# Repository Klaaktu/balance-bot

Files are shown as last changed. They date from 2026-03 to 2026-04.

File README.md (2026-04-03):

# PHS6701 Project 1 - Balance Bot

## Dependencies

Install these in Arduino IDE Library Manager
- Adafruit MPU6050 (IMU: Gyro + Acc)
- QMC5883LCompass by MPrograms (Magnetometer)
- Adafruit AHRS (Sensor fusion for absolute yaw)
- L298N by Andrea Lombardo (Motor driver)
- AdvancedPID by Alby312

## Calibration

You can remove the wheels so that it can sit flat on the ground.

## Libraries (for v1 code)

Version 1 uses code suggested by the instruction sheet, which is not in the Library Manager.

Copy the content of the `libraries` folder into the `libraries` folder in your Arduino sketchbook location (In Arduino IDE). You cannot have other libraries of the same functions installed or it's going to create a conflict.

## Notes
InvenSense has proprietary DMP 9-axis fusion which no one has working on Arduino. Open algorithm with I2C bypass works just as well. But you need raw readings, so can't use DMP or its interrupt. (The Adafruit lib doesn't support DMP readings either.)

MPU6050 max sample rate is 1kHz.

[Alternative rates](https://github.com/kriswiner/MPU9250/issues/363#issuecomment-502226744):
1k IMU and 100 mag, update rate 5k. Adafruit used 104Hz for IMU and 1k for mag, update rate 100Hz.

RIP, embedded software's documentations are so poor...

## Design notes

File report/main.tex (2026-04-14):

\documentclass[9pt,a4paper,twocolumn]{tau-class/tau}

\usepackage{listings}

\lstset{language=C++}

\title{Design a Robot with Balancing Ability and Self-controllability}

\author{Zhihao Lin\thanks{u8175491@anu.edu.au}}
\author{Zongjun Yang\thanks{u8463895@anu.edu.au}}

\affil[1]{Research School of Physics, Australian National University, Canberra ACT, 2601, Australia}

% \begin{abstract}
% \end{abstract}

\begin{document}

\maketitle

\section{Executive Summary / Abstract}
This report presents a comprehensive design review of an autonomous two-wheeled self-balancing robot, including system architecture, physical modeling, and current prototype progress. The primary objective is to develop a robot capable of maintaining dynamic balance, resisting external perturbations, and executing controlled motion. 

The proposed system architecture is driven by an Arduino UNO with a high-frequency Proportional-Integral-Derivative (PID) feedback control. Real-time spatial states sensing is acquired via an $I^2C$ MPU-6050 IMU. Actuation is delivered by two geared DC motors controlled by an L298N motor driver. Furthermore, the 3D-printed physical chassis was modeled using Lagrangian mechanics, intentionally increasing the height of mass center to lower the falling speed and provide the processor a temporal window for actuation.

As of Week 6, the project is progressing ahead of schedule. The physical prototype has been fully assembled, and the core balancing functionality has been successfully demonstrated. The robot can maintain steady-state equilibrium indefinitely with minimal drift ($<0.15m$ in 1s). While the current hardware configuration recovers from disturbances up to only $13^\circ$ (less than the $15^\circ$ target), the direction of mechanical and control improvements have been identified to resolve this during the next phase.

Moving forward, the team has transitioned to a concurrent engineering approach to develop advanced mobility and adaption skills in parallel. A revised timeline is used to map the final integration and comprehensive testing phases across Weeks 7-12.

\section{Introduction}

\subsection{Background}
There are increasing applications that need robots to participate. For example, complicated transportation in lab environments \cite{application_lab_transportation_liu_2013}, security support with interaction ability \cite{application_security_lopez_2017}, and educational communication \cite{application_social_tony_2018}. With the revolution of machine learning and artificial intelligence, robots are becoming much more intelligent \cite{ai_soori_2023, mobile_robot_raj_2022}, which will be applied to wider field.

Fundamentally, a robot requires several characteristics including: it must be produced by manufacture, it must be able to move itself or other objects, and it must be able to respond to its environment \cite{fundamental_todd_2012}. This indicates the essential parts of a robot: physical bodies, action drivers, sensors, and processors (controllers). Mobile robot is a typical case of both robot definition and robot applications \cite{mobile_robot_tzafestas_2018, mobile_robot_raj_2022}. 

To implement robots to everyday applications, we need to start from a prototype, and upgrade it step by step. The objective of this project is to design, fabricate, and program an autonomous robot with excellent balancing performance and high controllability. 

\subsection{Requirements Review}
\label{subsec:requirements_review}
The primary objective of this project is to build an autonomous self-balancing robot which is able to move to or keep itself around a designated position. To achieve this, the listed specific requirements are as follows:
\begin{itemize}
	\item Top-level requirements: \begin{itemize}
	\item The robot must maintain its balanced position without any falling cases.
	\item If the robot is perturbed externally (e.g., a deliberated push, or an obstacle collided), it must be able to return balanced within $2s$. The perturbation is defined as changing its pitch angle up to $15^\circ$.
	\item Without perturbation, the robot must balance itself in a small range. It must not move more than $0.5m$ in $1s$.
	\end{itemize}

	\item Electronic components:\begin{itemize}
	\item The robot must be able to sense its angle or velocity at $>100Hz$. The resolution of angle must be $<0.5^\circ$.
	\item The robot must take action within $0.1s$ after a controlling signal is sent.
	\item The electronics must be stable during its runtime.
	\item After turning on,  the robot must work entirely independently, including power supply, signal processing, and controlling.
	\end{itemize}

	\item Physical structure:\begin{itemize}
	\item The structure must be stable enough that the position of mass center doesn't change.
	\item The chassis must be sturdy, which can resist damage when the robot falls in some cases.
	\end{itemize}
  
  \item Advanced requirements: \begin{itemize}
  \item The robot can be able to fully control its state, including facing direction and moving speed.
  \item The robot can follow a designated path without obvious drift.
  \item The robot can dynamically adapt its response to varying operational environments: in peaceful environments, being slightly perturbed, being strongly perturbed, commanded to move to and keep around a position. 
  \end{itemize}
\end{itemize}

\section{Technical Details and Analysis}

\subsection{System Architecture}
\label{subsec:basic_ideas}

\figref{fig:basic_balancing_flowchart} shows the flowchart of the basic balancing idea of the robot. Generally, it shows the realization of the basic balancing skills. Any other advanced skills can be add to these parts. Reading multiple types of states (e.g., pitch angle, yaw angle, and x-acceleration) can be add in the "Read State" process. "Check States" decision can be used to assess the situation of the robot. "Feedback Controller" process can handle different controllers, such as PID controller. "Take Action" process controls the states of the robot.

\begin{figure}[htbp]
    \centering
    
    \caption{Flowchart of basic balancing logic. After turning on, the robot keeps reading its state, such as the pitch angle or the angular velocity of y-axis. If it's not strongly unbalanced, feedback controllers are used to generate an output from the state. The output is used to control the robot, such as moving forward or turn left. The feedback loop can balance the robot theoretically.}
    \label{fig:basic_balancing_flowchart}
\end{figure}

We started from developing the basic balancing skill. When this first stage was completed successfully, we would try to realize the advanced requirements by upgrading the existed processes or decisions instead of rebuild a new structure. In this way, the development would be controllable and the progress would be clear. However, a new structure can be required if we want to develop a more complex logic.

\subsection{Electronic Components}
To achieve the main goal, the electronic components should contain these necessary parts: a state sensor, a central processor, an action driver, and power supply.

\subsubsection{The state sensor}
We use MPU-6050 inertial measurement unit (IMU) as the state sensor. It consists of a triple-axis gyroscope and a triple-axis accelerometer. Using the angular velocities and linear accelerations, we can get or calculate most of the important states of robot. The key parameters of MPU-6050 are listed in \tabref{tab:mpu6050_specifications}:

\begin{table}[htbp]
    \centering
    \begin{tabular}{c c c}
    \toprule
    \textbf{Parameter} & \textbf{Value} & \textbf{Unit} \\
    \midrule
    Gyroscope Full-scale Range & $\pm250$ & $^\circ/s$\\
    Gyroscope Sensitivity & $131$ & $LSB/(^\circ/s)$\\
    Gyroscope Noise Spectral Density & $0.005$ & $^\circ/s/\sqrt{Hz}$\\
    Gyroscope Output Rate & $8000$ & $Hz$\\
    \midrule
    Accelerometer Full-scale Range & $\pm2$ & $g$\\
    Accelerometer Sensitivity & $16384$ & $LSB/g$\\
    Accelerometer Noise Spectral Density & $400$ & $\mu g/\sqrt{Hz}$\\
    Accelerometer Output Rate & $1000$ & $Hz$\\
    \midrule
    Supported Communication & $I^2C$ & \\
    Communication Speed & $400$ & $kHz$ \\
    Clocking Speed & $32.768k\sim19.2M$ & $Hz$ \\
    \midrule
    Power Input Voltage & $2.375\sim3.46$ & $V$ \\
    \bottomrule
    \end{tabular}
    \vspace{\baselineskip}
    \caption{The key parameters of MPU-6050 inertial measurement unit \cite{mpu6050_datasheet}}
    \label{tab:mpu6050_specifications}
\end{table}

The best resolution of angular velocity can reach $7.6\times10^{-3}\;^\circ/s$, and the best resolution of acceleration can reach $61\times10^{-6}\;g$. Ignoring the noise, these resolutions are totally sufficient for the requirements. Both the sampling rate and communication speed satisfy our requirements. The primary limitation of this IMU is the inherent sensor noise or drift. Considering the noise, we can try to process the signal (such as low-pass filter or quaternion) to get high enough resolution. 

\subsubsection{The central processor}
Arduino UNO is chosen as the processor. We can use it to get data from the IMU, process the data, and control the action driver. Its key parameters are listed in \tabref{tab:arduino_uno_specifications}:

\begin{table}[htbp]
    \centering
    \begin{tabular}{c c c}
    \toprule
    \textbf{Parameter} & \textbf{Value} & \textbf{Unit} \\
    \midrule
    \# Digital I/O Pins & $14$ & \\
    \# Analog Input Pins & $6$ & \\
    \# PWM Pins & $6$ & \\
    \midrule
    Supported Communication & $I^2C$, $SPI$, $UART$ & \\
    Clocking Speed & $16$ & $MHz$ \\
    \midrule
    Power Output Voltage & $3.3$, $5$ & $V$ \\
    Power Input Voltage & $7\sim12$ & $V$ \\
    \bottomrule
    \end{tabular}
    \vspace{\baselineskip}
    \caption{The key parameters of Arduino UNO \cite{arduino_uno_datasheet}}
    \label{tab:arduino_uno_specifications}
\end{table}

The number of digital, analog and PWM pins are enough for the wiring connecting the processor to the sensor and the action driver. The high processing speed is ideal for our control logic. Using $I^2C$ communication and $3V3$ output power, it can match the MPU-6050 very well. However, the power output voltage may not be enough for some action drivers. So a shared power supply may be required. 

\subsubsection{The action driver}
We choose to use a L298N motor driver and two geared DC motors. The key parameters of the L298N motor driver are listed in \tabref{tab:l298n_specifications}:

\begin{table}[htbp]
    \centering
    \begin{tabular}{c c c}
    \toprule
    \textbf{Parameter} & \textbf{Value} & \textbf{Unit} \\
    \midrule
    Digital Input Pins & $IN1+IN2$, $IN3+IN4$ & \\
    PWM Input Pins & $ENA$, $ENB$ & \\
    \midrule
    Logic Input Voltage & $5$ & $V$ \\
    Power Output Voltage & $3.2\sim40$ & $V$ \\
    Power Input Voltage & $5\sim35$ & $V$ \\
    \bottomrule
    \end{tabular}
    \vspace{\baselineskip}
    \caption{The key parameters of L298N motor driver \cite{l298n_datasheet}}
    \label{tab:l298n_specifications}
\end{table}

The motor driver allows PWM input, which matches well with the Arduino UNO. The digital input pins can be used to control the direction of motors, while the PWM input pins can be used to control the speed. The required voltage is high as expected, so a good power supply is needed. However, by experiments, we found that the motors can keep still when the speed signal is small, which is caused by the internal static friction. Feed-forward controller can be added to solve this dead-band. Moreover, the two motors have a little asymmetry, which makes the robot yaw. Therefore, stepper motors can be required when we need to do precise control or measurement.

\subsubsection{Power supply}
We need to supply power to both the Arduino UNO and the motor driver. Therefore, two 800mAh 3.7V rechargeable Li-ion cells are used. For reusability, we use a breadboard to transfer the power from batteries to the two components instead of soldering the wires. The safe charged voltage of Li-ion is $2.8\sim4.2\;V$. By testing, the batteries need to be recharged after working for about 10 hours. 

\subsubsection{Wiring structure}
As mentioned above, the electronic components used are: 
\begin{itemize}
  \item MPU-6050 IMU
  \item Arduino UNO
  \item L298N motor driver
  \item Geared DC motors
  \item Li-ion Batteries
  \item Breadboard
\end{itemize}
The wiring method is shown in \figref{fig:wire_diagram}.

\begin{figure}[htbp]
    \centering
    
    \caption{Wiring diagram of the electronic components. The battery and breadboard are used to power the Arduino UNO and L298N motor driver. UNO communicates with MPU-6050 inertial measurement unit (IMU) using I2C protocol, and sends analog signal to the motor driver using pulse width modulation (PWM). The motor driver controls 2 motors.}
    \label{fig:wire_diagram}
\end{figure}

\subsection{Mechanical Design}

\subsubsection{Physical model analysis}
\figref{fig:physical_model} shows the simplified physical model of the robot. We can use Lagrangian mechanics to analyze the relationship between $F$ and $\theta$, $x$. The system Lagrangian and Euler–Lagrange equations are given by:
\begin{equation}
	L=\frac{1}{2}M\dot{x}^2+\frac{1}{2}m\left[(\dot{x}+l\dot{\theta}\cos{\theta})^2+(l\dot{\theta}\sin{\theta})^2\right]-mgl\cos{\theta}
\end{equation}
\begin{align}
	\frac{d}{dt}\frac{\partial L}{\partial\dot{x}}-\frac{\partial L}{\partial x}=F\quad&\Longrightarrow\quad(M+m)\ddot{x}+ml\ddot{\theta}\cos{\theta}-ml\dot{\theta}^2\sin{\theta}=F\label{eq:el_eq1}\\
	\frac{d}{dt}\frac{\partial L}{\partial\dot{\theta}}-\frac{\partial L}{\partial\theta}=0\quad&\Longrightarrow\quad \ddot{x}\cos{\theta}+l\ddot{\theta}-g\sin{\theta}=0\label{eq:el_eq2}
\end{align}

\begin{figure}[htbp]
    \centering
    
    \caption{A simplified physical model of the robot. Constrain the movement in 1 dimension. THe model consists of a wheel with mass $M$, a body mass center $m$, and a light stick connecting these two with length $l$. The action of wheel is simplified as a force $F$. Assume the robot is at position $x$ and its pitch angle is $\theta$.}
    \label{fig:physical_model}
\end{figure}

Usually, we care about the dynamic of $\theta$, which can be derived from \equref{eq:el_eq1} and \equref{eq:el_eq2}:
\begin{equation}
	\ddot{\theta}=\frac{(M+m)g\sin{\theta}-F\cos{\theta}}{(M+m\sin^2{\theta})l}-\frac{m\dot{\theta}^2\sin{2\theta}}{2(M+m\sin^2{\theta})}
    \label{eq:theta_dynamic}
\end{equation}

According to the model \figref{fig:physical_model} and this \equref{eq:theta_dynamic}, we can analyze some cases:
\begin{itemize}
	\item The robot is perfectly at the balanced state, but a perturbation happens before the controller realizes it (i.e., $\theta\gtrapprox0$, $F=\dot{\theta}=0$). In this case, $\ddot{\theta}\approx\frac{(M+m)g\sin{\theta}}{lM}$. To maximize the controller's temporal response window before $\theta$ reaches an unbalanceable angle, we want $\ddot{\theta}$ to be as small as possible, which means we need to use small $m$ and/or large $l$.
	\item The robot is in a state of dynamic equilibrium (i.e., $\theta>0$, $\ddot{\theta}\approx\dot{\theta}\approx0$). To keep a constant $\theta$, it's necessary to make $F=(M+m)g\tan{\theta}$. However, because of the limit of motor power, $F$ can be maintained for only a short time before the large speed brings large resistance. So we should make $F>(M+m)g\tan{\theta}$ to bring back balance before the saturation of motors.
	\item The robot is severely unbalanced (i.e., $\theta>0$, $\dot{\theta}>0$). In this case, the only possible way to balance the robot is to make $\ddot{\theta}$ as negative as possible (i.e., $\ddot{\theta}\ll0$). To achieve this, we need to use a combination of large $F>(M+m)g\tan{\theta}$ and small $l$.
	\item The robot is inverted (i.e., $90^\circ<\theta<270^\circ$ ($l<R_\text{wheel}$), $l=0$, or $m=0$). Now the robot is impossible to return to the desired balanced state (or the balanced state can't be defined), but becomes permanently stable.
\end{itemize}
In conclusion, a motor being able to produce huge $F$ is wanted for all the cases. Similarly, it's good to have small $m$, $M$, and/or $\frac{m}{M}$. Large $l$ is suitable for peaceful environment and high balance performance, while small $l$ or inverted robot is suitable for severe environment and high controllability. 

\subsubsection{Chassis}
We use CAD (Autodesk Fusion) to design the chassis model, and 3D-print the model. The chassis is designed with many components in the experimental stage to make some components easier to update. These components are assembled using M3 bolts and nuts. For the final design, all the components are combined into a whole one to make the chassis stable.

In Fusion, the chassis is designed with the help of the models of other electronic components. Official datasheets of the electronic components are also used. In this way, it's precise and accurate to design the size and position of chassis components and through holes. One of our CAD model designs is shown in \figref{fig:chassis_design}. It has high mass center, which can perform good balancing skill but lack flexibility.
\begin{figure}[htbp]
  \centering
  \begin{subfigure}{0.8\columnwidth}
    
    \caption{Front-top-side view}
  \end{subfigure}

  \vspace{\baselineskip}

  \begin{subfigure}{0.8\columnwidth}
    
    \caption{Robot components and assembly}
  \end{subfigure}
  \caption{A chassis model design.}
  \label{fig:chassis_design}
\end{figure}

PrusaSlicer is used to convert CAD models to 3D-printing code. The printer uses PLA as the filament with diameter of $1.75mm$. To make our chassis sturdy, we use layer height of $0.3mm$. The vertical shells is set to 4 perimeters, and the horizontal shells is set to 4 top layers and 4 bottom layers. Since most of our chassis consist of plates of $3mm$, these parameters are sufficient to make our chassis solid. The fill density is set to $15\%$. The only disadvantage is that solid chassis may increase the mass. We compensated it by change the height of mass center by a larger value.

\subsection{Signal Processing}

\subsubsection{IMU data processing}
To get the robot state, we need to process the data from the IMU. The IMU contains a 3-axis gyroscope used to measure angular velocity and a 3-axis accelerometer used to measure acceleration. One important thing we can do is to get the angle (yaw, pitch, roll) from these values. Simply, we can integrate the 3 angular velocities $(\omega_x,\omega_y,\omega_z)$ to get the corresponding Euler angle. However, Euler angles suffer from Gimbal Lock, resulting in the loss of a degree of freedom and causing ambiguous calculations (for example, the results are the same whether it yaws by $30^\circ$ and then pitches by $90^\circ$, or pitches by $90^\circ$ and then rolls by $30^\circ$, which makes it difficult to determine the true yaw or roll angle). Because of this, we use quaternion $q=(q_0,q_1,q_2,q_3)$ to represent the angle state, which indicates the current state that is equivalent to rotate the initial state around an axis $(q_1,q_2,q_3)$ by an amount of $q_0$. The current quaternion is given by:
\begin{equation}
	q_n=q_{n-1}+\frac{\Delta t}{2}\cdot q_{n-1}\otimes\omega
\end{equation}

Another method to get quaternion is using the accelerations $(a_x,a_y,a_z)$. Because there is a constant gravity of $\approx9.8m\cdot s^{-2}$, we can know the quaternion by comparing the direction of measured acceleration with the true gravity. However, this method is noisy, while using gyroscope can produce drift over a long time. We can mitigate the high-frequency noise of accelerometers by a low-pass filter, and the low-frequency drift of gyroscopes by a high-pass filter, which is called complementary filter.

There are many states we can calculate from the quaternion (Most calculations can be done by the IMU module or some libraries such as \texttt{i2cdevlib/Arduino/MPU6050}). For example:
\begin{align}
	\text{Pitch: }&\theta=\arcsin{(2(q_0q_2-q_3q_1))}\\
	\text{Yaw: }&\psi=\arctan{\frac{2(q_0q_3+q_1q_2)}{1-2(q_2^2+q_3^2)}}\\
	\text{Acceleration: }&a_\text{world}=q\otimes(0,a_x,a_y,a_z)\otimes q^{-1}
\end{align}

In this way, we can get the tilt angles or accelerations much more precisely and unambiguously. However, to get the displacement of the robot, we need to integrate the acceleration twice, which can brings huge noise and drift. This disadvantage is mostly caused by the hardware, which is hard to improve by software. Therefore, we can choose to calculate the displacement from the signal used to control the speed of motors.

\subsubsection{PID controller}
PID (Proportional-Integral-Derivative) controller is the core of the feedback system. By comparing the current state $S(t)$ with the desired state, we get an error term $e(t)$. Using $e(t)$ as the input of PID controller, we can use the output $u(t)$ to drive the current state toward the desired state. The output expression is given by:
\begin{equation}
	u(t)=K_pe(t)+K_i\int_{0}^{t}{d\tau\,e(\tau)}+K_d\frac{de(t)}{dt}
\end{equation}

The Proportional term means that the larger the error is, the large the output is to restore the state. The Integral term means that the longer the error persists, the large the output is to further restore the state. The Derivative term means that the faster the error decreases, the smaller the output is to reduce oscillation. The three terms have individual coefficients ($K_p$, $K_i$, $K_d$). Their combinations vary widely across different situations.

For the PID of balancing pitch angle, the 3 coefficients need to be tune along with the balanced pitch angle $\theta_0$. First, we found the approximate pitch angle. Based on this, we adjusted only $\theta_0$ and $K_p$ until the robots fell in both directions with a similar low probability, which means $\theta_0$ is closed to the true balanced pitch angle. Then, we tuned $K_d$ such that the robot wouldn't oscillate too much around the $\theta_0$. However, the robot may occasionally keep moving in one direction. We used large $K_i$ to correct it. The optimal tuning yields highly varied coefficients. For example, $K_p=48$, $K_i=600$, and $K_d=0.19$ with PID sample time $=2ms$. By tunning these coefficients and looking for a good balancing state, we can achieve better feedback performance. 

\subsubsection{Pulse width modulation}
In order to control the robot smoothly and continuously, we need analog signals to do the task. However, the UNO has only digital output, which means the output voltage can be either HIGH level or LOW level without any values in between. PWM can solve this problem. Instead of encoding signals to voltage level, it produces a train of pulses as the output, and encodes signals to the width of each pulse. Meanwhile, our motor driver is able to receive the PWM signals.

However, the range of PWM values is limited. This disadvantage can be ignored in our cases, since the resolution of PWM is much better than the resolution of geared motors.

\subsection{Control Logic}
The program for controlling runs in Arduino UNO. The structure of control logic is based on \ref{subsec:basic_ideas} and \figref{fig:basic_balancing_flowchart}, whose details are shown below:

\subsubsection{Start}
In this initialization sequence, all the components are configured. If anyone of them is not initialized successfully, the following controlling code would not run.
\begin{itemize}
  \item \texttt{initImu()}: Sets the offsets of 3 axises for the gyroscope and the accelerometer, and waits until the IMU becomes stable.
  \item \texttt{initPID()}: Defines the balanced pitch and yaw, the PID coefficients for different situations, and the PID object for pitch and yaw.
  \item \texttt{initMotor()}: Uses \texttt{pinMode(pin, mode)} to initialize 2 EN pins and 4 IN pins.
\end{itemize}

\subsubsection{Read States}
In this process, we get the states of the robot from the calculations about quaternion. The logical code is shown in \coderef{lst:code_read_states} For pitch and yaw angles, we calculate the error between the true angle and the balanced angle, unwrap the $2\pi$ period, and use the result as the input of feedback control. For accelerations, we compute the value in the world frame using the quaternion.

\begin{lstlisting}[caption={Example code of "Read States" process}, label={lst:code_read_states}]
double unwrapAngle(float angle, double balanced) {
  double a = angle * 180 / M_PI - balanced;
  // ... unwrap from 2*pi ...
}
bool getRobotState() {
  imu.dmpGetQuaternion(&quaternion, imuFifoBuffer);
  imu.dmpGetYawPitchRoll(imuYpr, &quaternion, &gravity);
  pitchAngle = unwrapAngle(imuYpr[1], balancedPitch);
  // ... doing similar jobs for yaw and acceleration ...
  imu.dmpGetLinearAccelInWorld(...);
}
\end{lstlisting}

\subsubsection{Check States}
The states gotten from the previous process is analyzed, and the next step is determined. For example (as shown in \coderef{lst:code_check_states}), the coefficients of PID controller will dynamically transition to surviving mode (high-gain feedback) if the pitch angle is too large, or the motors will be disabled if the robot is destined to fall.

\begin{lstlisting}[caption={Example code of "Check States" process}, label={lst:code_check_states}]
if (abs(pitchAngle) > maxPitchAngle) { motorStop(); }
// ...
if (abs(pitchAngle) > survivingPitch) {
  pitchPID.SetTunings(sKp, sKi, sKd);
} else { pitchPID.SetTunings(kp, ki, kd); }
\end{lstlisting}

\subsubsection{Feedback Control}
Our feedback control is currently based on only PID controller. We use a library to manage the computing. In the code, the feedback output can be gotten from \texttt{pid.Compute()}. The code is simple, while this process is essential to the robot. All the coefficients need plenty of time to tune manually.

\subsubsection{Take Action}
This process convert the digital signals from feedback control into a real action of the robots. For example, accelerating immediately, or rotating clockwise slowly. The action is also influenced by "Check States". As shown in \coderef{lst:code_take_action}, balancing the pitch is a priority over adjusting the yaw.
\begin{lstlisting}[caption={Example code of "Take Action" process}, label={lst:code_take_action}]
if (abs(motorValue) > maxMotorValue * 0.3) {
  motorMove(motorValue, ENA_PIN, IN1_PIN, IN2_PIN);
  motorMove(motorValue, ENB_PIN, IN3_PIN, IN4_PIN);
} else {
  motorMove(motorValue + yawCorrection, ENA_PIN, ...);
  motorMove(motorValue - yawCorrection, ENB_PIN, ...);
}
\end{lstlisting}

\section{Prototype Progress}

\subsection{Current Prototype Capabilities}

During the last 6 weeks, we have finished these tasks: connecting and initializing each components, reading angles and accelerations from IMU, using PWM to driver motors, balancing the robot by its pitch angle with PID, controlling the yaw angle basically.

The robot of current version is shown in \figref{fig:robot_balancing_on_table}. 

\begin{figure}[htbp]
    \centering
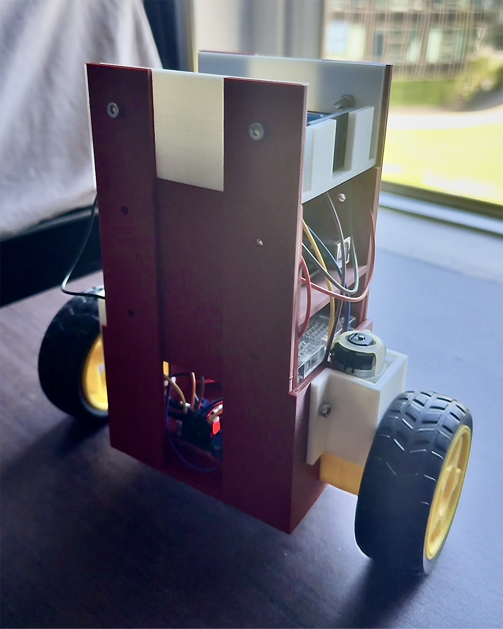
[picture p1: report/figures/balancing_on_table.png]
    
    \caption{The robot with complete basic balancing skills and preliminary advanced skills. It can stably balance itself on a small table.}
    \label{fig:robot_balancing_on_table}
\end{figure}

Preliminary performance metrics of the current prototype are listed in \tabref{tab:robot_evaluation_metric}. Most top-level requirements mentioned in \ref{subsec:requirements_review} are achieved. Some evaluations are even better than expected, such as the max displacement in 1s  without perturbation. However, the max allowed perturbation pitch ($<15^\circ$) is not achieved. It's because the high mass center can weaken its perturbation resistance. To improve this skills, we will try to increase the strength of motor driver, increase the wheel size, or decease the mass and the height of mass center.

\begin{table}[htbp]
    \centering
    \begin{tabular}{c c}
    \toprule
    \textbf{Evaluation Metric} & \textbf{Rough Value} \\
    \midrule
    Balancing Time (no perturbation) & $\sim\infty$ \\
    Max Pitch (no perturbation) & $\approx3.5^\circ$ \\
    Max Displacement in $1s$ (no perturbation) & $\approx0.15\;m$ \\
    Min Pitch to Drive Motors & $<0.4^\circ$ \\
    \midrule
    Perturbation Reaction Time & $\ll0.2\;s$ \\
    Max Allowed Perturbation Pitch & $\approx13^\circ$ \\
    Max Time to Restore from Pitch Perturbation & $\approx1.5\;s$ \\
    Max Displacement by Pitch Perturbation & $\approx1\;m$ \\
    Max Time to Restore from Yaw Perturbation of $180^\circ$ & $\approx3\;s$ \\
    \bottomrule
    \end{tabular}
    \vspace{\baselineskip}
    \caption{Some key evaluations of the robot of current version.}
    \label{tab:robot_evaluation_metric}
\end{table}

\subsection{Current State}
It's the 6th week. We are mainly focusing on the reports and the review of the last 6 weeks. Meanwhile, we also start to design or improve the prototype to achieve the advanced requirements. These tasks are being done: controlling the yaw angle with high flexibility, and controlling the linear motion at a constant speed with good balance performance. 

\section{Project Management}

\subsection{Responsibilities}
Initially, the project was divided into two parts: hardware and software. The origin responsibilities are listed below:
\begin{itemize}
  \item Lin: hardware part, including electronic components and mechanical design
  \item Yang: software part, including signal processing and control logic
\end{itemize}
However, our progress was unexpectedly fast. The first version of balancing robot was developed much earlier than planned. After discussions, we both agreed that designing the hardware and software together is much more efficient than designing them individually and then combining them. By team working and peer learning, we quickly mastered both the hardware and software part. Therefore, we use a semi-parallel structure for our project. Both of us is responsible to design a robot with different skills individually while sharing the same mechanical and logical architecture. There are also regular discussions about integrating these skills into one robot. Our current responsibilities about skill designing are listed below: 
\begin{itemize}
  \item Lin:\begin{itemize}
    \item Locking skill: the robot can lock itself to a certain direction, even if it's rotated by us deliberately.
    \item Adaption skill: the robot can judge the situation that it's facing or will face.
  \end{itemize}
  \item Yang:\begin{itemize}
    \item Motion skill: the robot can move forward and backward actively while keeping balanced.
    \item Resurrection skill: the robot can restore itself from a heavy perturbation.
  \end{itemize}
\end{itemize}
Combining these skills, we can achieve the advanced requirements mentioned in \ref{subsec:requirements_review}

\subsection{Estimated Timeline}
The remaining development will be divided into 3 phases:
\begin{itemize}
  \item Phase 1: Improve the locking skill and motion skill. Combine them into one robot.
  \item Phase 2: Develop the adaption skill and resurrection skill. Discuss the development plans in the beginning, and combine the development results at the end.
  \item Phase 3: Conduct comprehensive tests. Do the final improvements based on the performance.
\end{itemize}
The detailed timeline is shown in \figref{fig:timeline_gantt_chart}
\begin{figure}[htbp]
    \centering
    
    \caption{The Gantt chart of our estimated timeline.}
    \label{fig:timeline_gantt_chart}
\end{figure}

\subsection{Budget}
The project was designed to be cost-efficiency for rapid prototyping, utilizing off-the-shelf hardware and open-source software libraries. While the primary components were provided for this study, the total retail cost for the electronics and mechanical parts is approximately \$120 AUD. Additionally, iterating the chassis design via 3D printing cost less than \$5 AUD in material costs. This low-cost approach ensures the platform remains accessible for replication and future development.

\section{Conclusion}
This design review has detailed system architecture, mathematical and physical foundations, and developmental progress of an autonomous balancing robot. By leveraging a Lagrangian dynamic model, the physical chassis was currently optimized with an elevated center of mass. System requirements have been addressed through a robust electronics stack, utilizing an $I^2C$ MPU-6050 IMU. A 500 Hz PID control loop effectively translates error calculations into physical restoration via the L298N motor drivers. Current prototype testing confirms the viability of this design; the robot successfully maintains steady-state dynamic equilibrium with minimal drift and recovers from impulse perturbations up to $13^\circ$.

While the current perturbation resistance falls marginally short of the $15^\circ$ target, the identified hardware limitations provide a clear pathway for refinement. As the project enters the final phases of development, the transition to a concurrent engineering strategy ensures that advanced mobility and adaptation skills will be integrated efficiently.

\printbibliography

\end{document}

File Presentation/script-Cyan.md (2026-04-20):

I should **first acknowledge** that I'm basically being carried by my teammate here. What's been completed **is all his work**. I have some **ideas but unfortunately** I didn't have time to finish them. But I'll **integrate** those ideas to the presentation.

# Chassis

So um, I made another iteration of the chassis in **FreeCAD**. It's meant to be more **modular** and **lighter** plus some **minor improvments**. However the biggest **problem** I created is that it's hard to **assemble** because the **screws** are hard to access. I plan to change to **horizontal screw tabs** next time.

# Signal Processing: IMU

**The IMU has** gyroscopes and accelerometer, and in some chip packages like mine, has a magnetometer as well. The **gyroscopes measures** the angular velocity and the **accelerometer measures** the acceleration.

To get the pitch we need to do **sensor fusion**. It can be done by either **FOSS libraries or the proprietary DMP** on the MPU6050.

The reasons are:

1. None of the sensors measure positions, only **derivatives**. If you just integrate gyro without an absolute reference you only have a **relative position** to where it started.
The accelerometer gives a **vertical reference** which is the gravity, for the pitch and roll. And the magnetometer gives a **horizontal reference** which is north, for the yaw.
2. Sensor fusion algorithms **compensate for the weakness** in each sensor that can't be removed by **calibration**. (e.g. temperature drift in gyro.)

I use the cheapest and fastest algo called **Mahony**.

Internally those algorithms use **Quaternions** to represent orientation, which is better than Yaw Pitch Roll or Euler angles, because it doesn't have the **gimbal lock problem** (You lose a DoF and can't move in that direction in some orientation). But for our use case, **pitch is the most straightforward**.

# Signal Processing: PID controller

The **angle** can deviate from the balanced state. The **PID controller** determines how much to **drive the motor** to fix the error. 

There are three parts of PID controller. The **explanation in the instruction** is pretty good, but here's a breakdown:

1. P - Proportional. The proportional response is **proportional to the error**. (Error is how much the angle deviates from neutral.)
2. I - Integral, looks at the *past*. The integral response is based on the **accumulated error** over time. It drives the **steady-state error to 0**. Because for as long as an **error exists, it continues to grow**.
3. D - Derivate, predicts the **future**. It looks at the **trend** of the error and adjust accordingly.

It's very important to find a good combination of these coefficients. But here is a trick, we can just use the **gyro reading for the derivative term**. The Y angluar velocity is exactly the change in pitch. You can do this in the **AdvancedPID** library,

The calibration steps:

1. Start with every thing at zero.
2. Tuned the set point (balanced angle) and K_p together, until the robot ocillates in both direction with similar probability.
3. Use gyro Y for K_d.
4. Increase the Ki, so that the steady-state error is 0 (does not keep moving in one direction without restoring the angle).
5. Trial & Error fine tuning.

# Control Logic

The control loop is basically shown like here.

We read the pitch and gyro, checks what to do, calculates PID output, then drive the motor.

My difference was that I use libraries for every component, so that it's more straightforward. **Separating** myself from **calculations** and **raw input / output**.

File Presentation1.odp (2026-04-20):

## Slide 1


Design a Robot with Balancing Ability and Self-controllability

Team:

Members:

Box3

Zhihao Lin (u8175491@anu.edu.au)

Zongjun Yang (u8463895@anu.edu.au)

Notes: ‹#›

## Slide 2

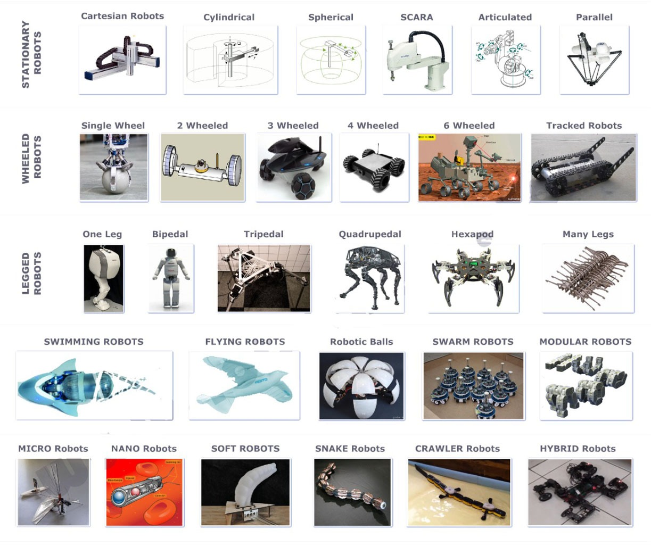
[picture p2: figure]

Types of robots [2]

Industry robots [1]

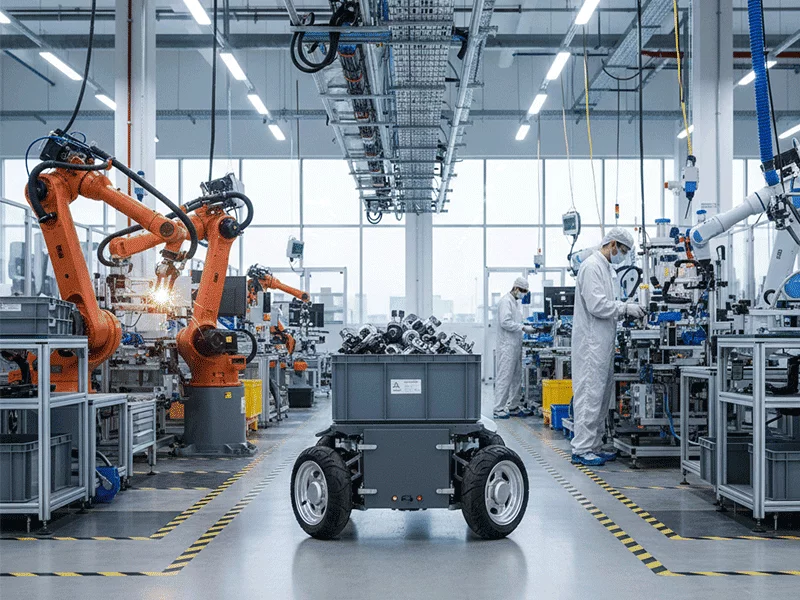
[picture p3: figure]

Background

Requirements Review

Top-level requirements

- Maintain its balanced state
- Drift less than 0.5m in 1s
- Recover from 15° perturbation within 2s

Advanced requirements

- Fully control its state
- Follow a designated path
- Dynamically adapt to varying environments

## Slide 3

MPU-6050 IMU

“The state sensor”

- Angular velocity res:
- Acceleration res:
- Features: I2C
- Communication speed: 400 kHz

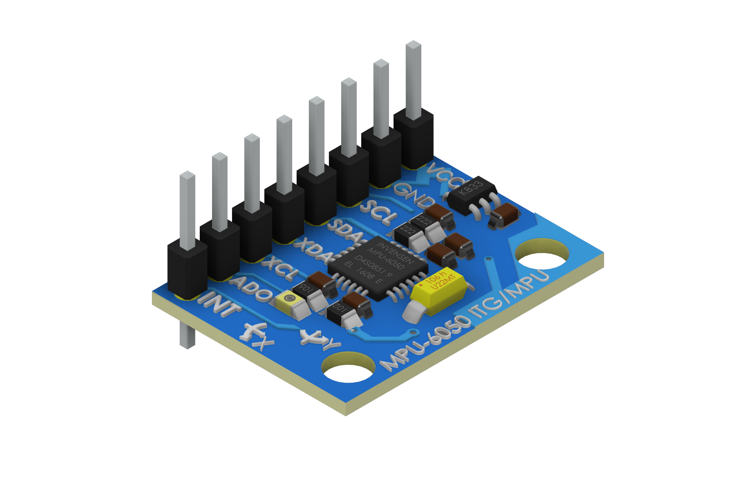
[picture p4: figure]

Arduino UNO

“The central processor”

- Clocking speed: 16 MHz
- Features: I2C, PWM

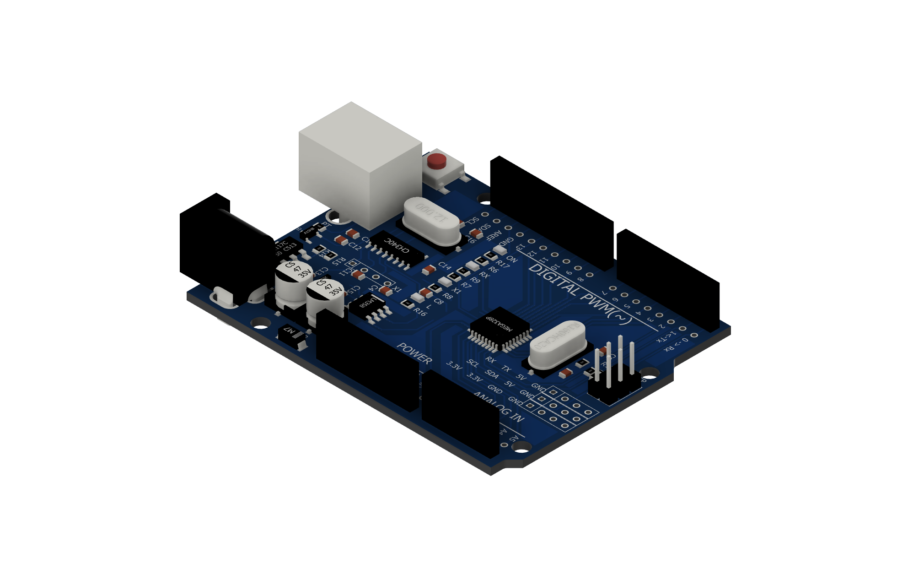
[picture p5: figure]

L298N motor driver

“The action driver”

- Power output: 3.2 - 40 V
- Features: PWM

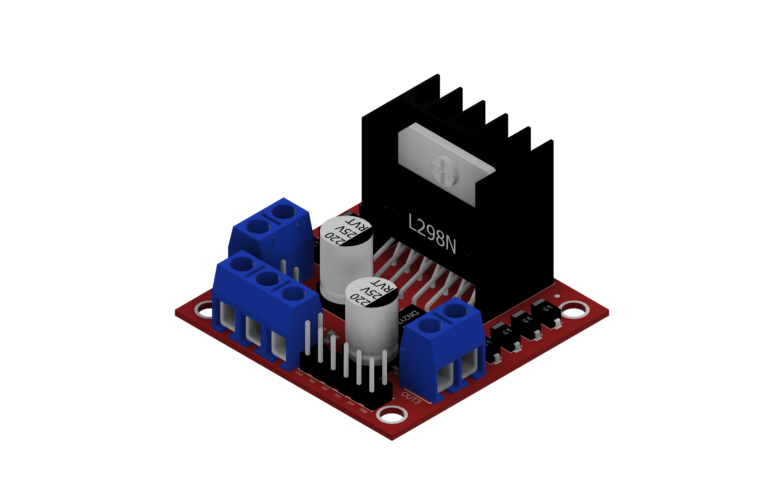
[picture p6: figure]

System Architecture

Electronic Components

Li-ion cell

“The power supply”

- Capacity: 800 mAh
- Nominal voltage: 3.7 V

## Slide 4

Mechanical Design: Physical Model

Case 1: tiny perturbation ( , )

- We want to be as small as possible
- We need large l and small m

Case 2: dynamic equilibrium (, )

- We want to recover as soon as possible
- We need

Use Lagrangian mechanics:

Case 3: severely unbalanced (, )

- We want as negative as possible
- We need and small l

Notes: ‹#›

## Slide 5

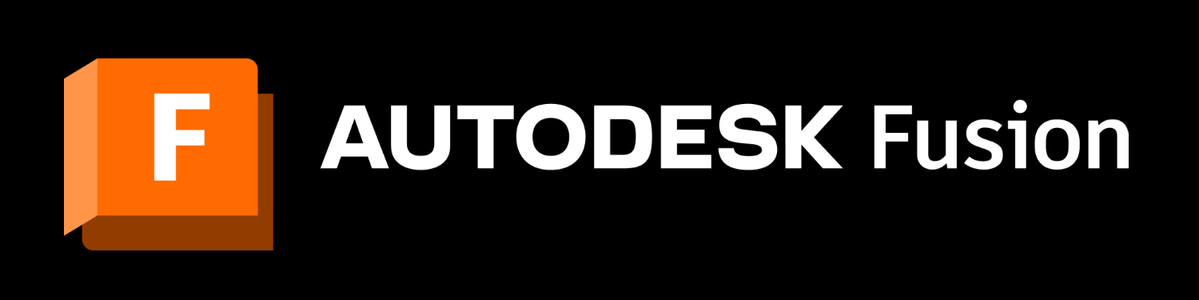
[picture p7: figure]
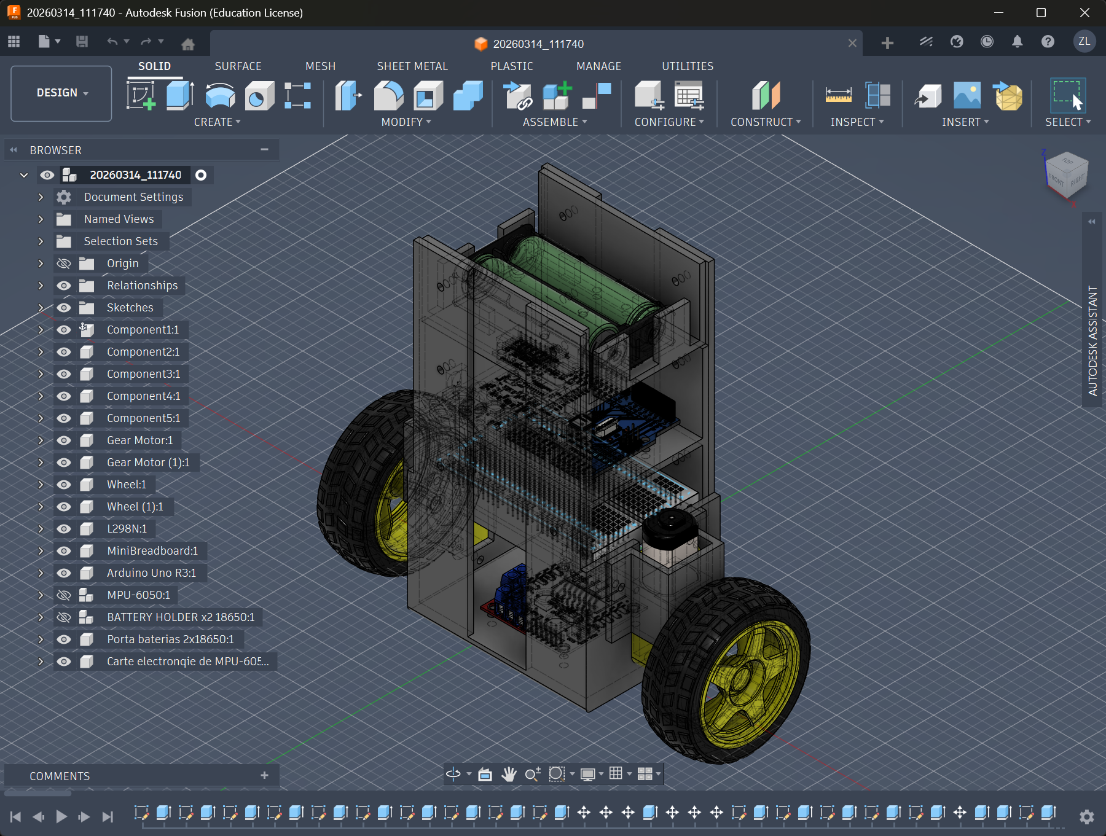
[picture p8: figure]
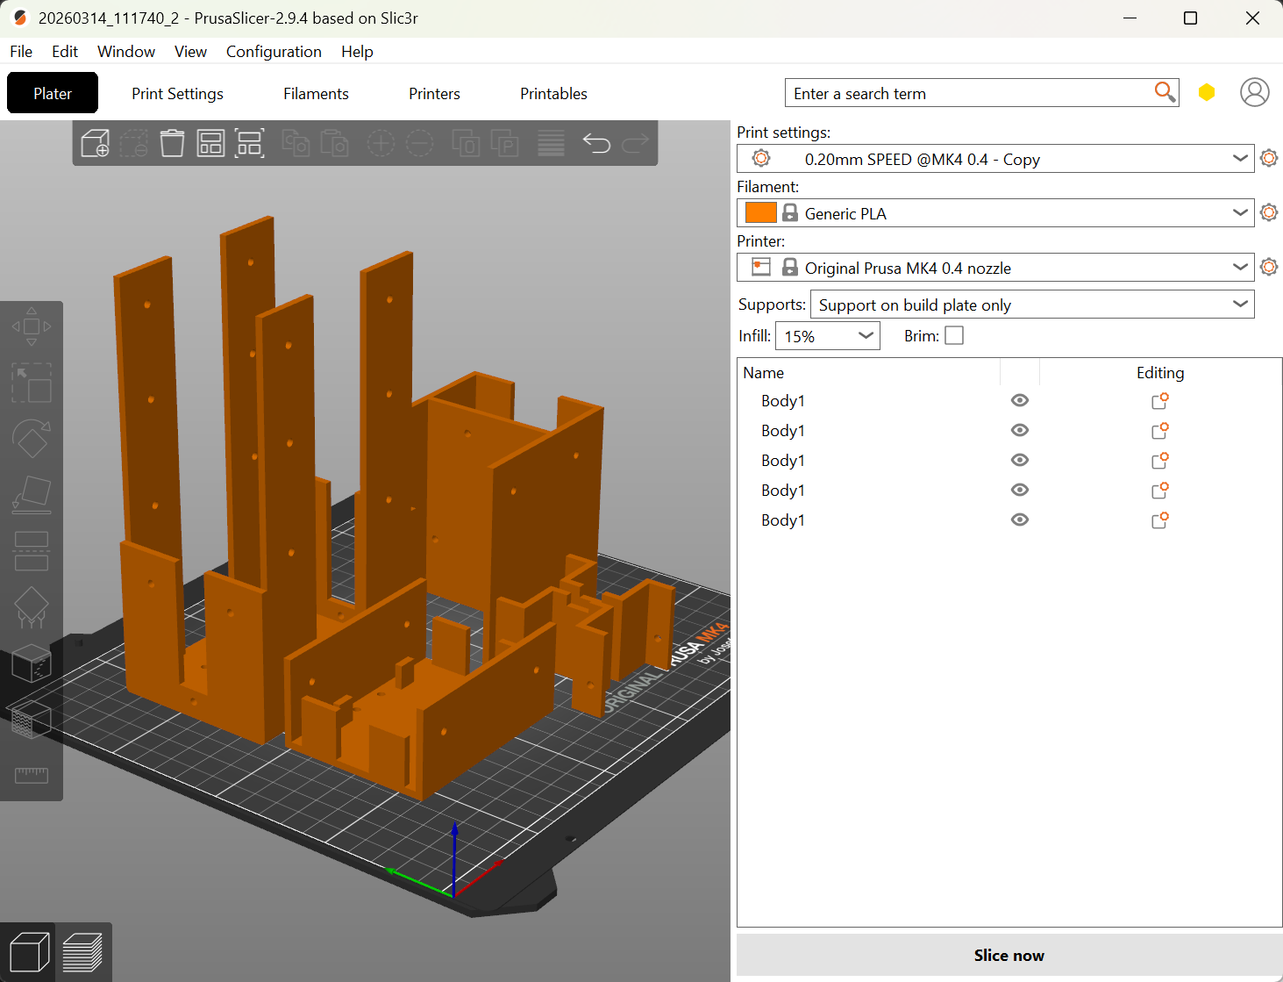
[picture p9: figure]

Mechanical Design: Chassis and Assemble

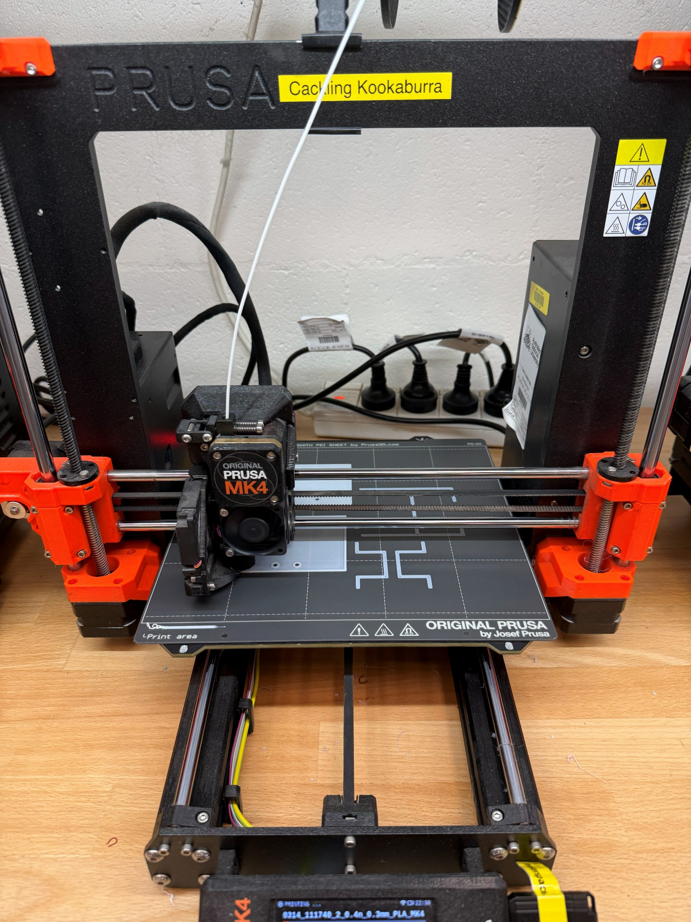
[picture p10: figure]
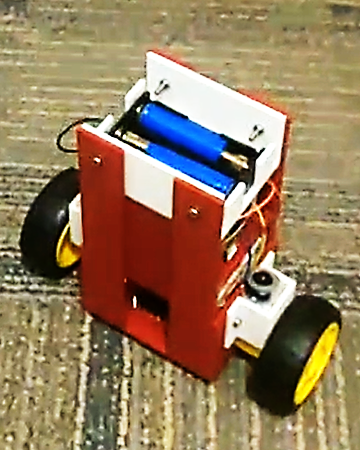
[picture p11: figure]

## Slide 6

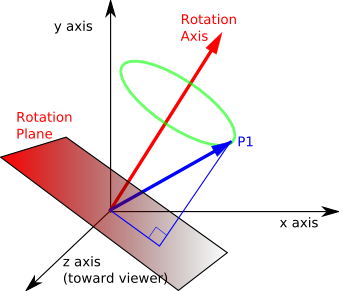
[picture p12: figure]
Quaternions

Quaternions [3]

Quaternion

- Represents the current state
- Shows the object has rotated around by
- More efficient and stable than Euler angles
- Update state:

Sensor Fusion

Gyroscope

- Measure angular velocities
- Give yaw, pitch, and roll by integrating
- Cons: drift over time

Accelerometer

- Measure accelerations
- Determine pitch and roll from gravity direction
- Cons: noisy

Magnetometer

- Measure magnetic field
- Determine yaw from Earth’s magnetic field
- Cons: easily disturbed

Fusion

- Complementary Filter
- Mahony Filter
- …

Signal Processing: IMU

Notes: 6

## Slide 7

Proportional

Integral

Derivative

the larger the error is, the large the output is to restore the state

the longer the error persists, the large the output is to further restore the state

the faster the error decreases, the smaller the output is to reduce oscillation

Signal Processing: PID Controller

Error term e(t): difference between the current state S(t) and the desired state

Output u(t): used to drive the current state toward the desired state

Tune

Tune and find better combination of

Tune and

Tune

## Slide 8

Control Logic

Read States

- Calculate pitch, yaw, …
- Calculate acceleration in the world frame
- …

Check States

- Determine whether the pitch is recoverable
- Estimate the perturbation
- …

Feedback Control

- Calculate the output of PID controller
- Use other feedback logics
- …

Take Action

- Further adjust the controller output
- Control the motors
- …

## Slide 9

Current Progress

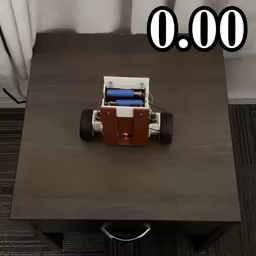
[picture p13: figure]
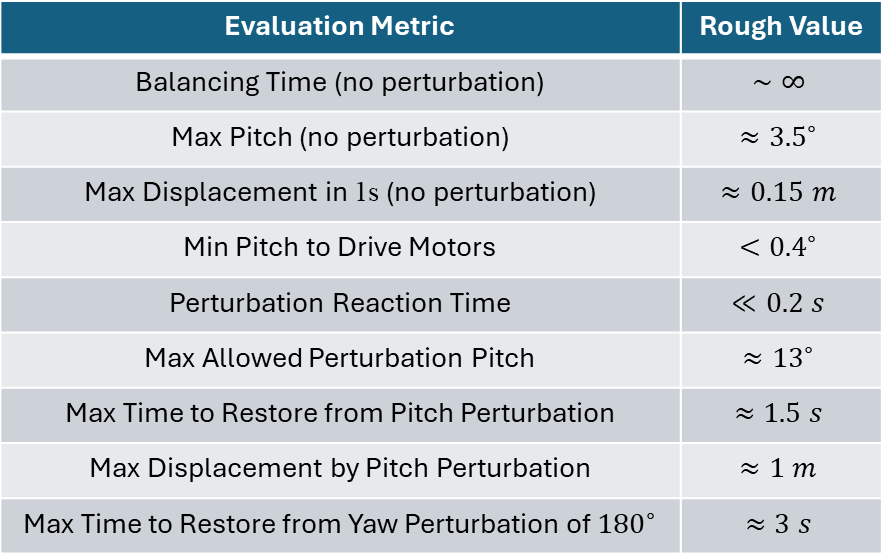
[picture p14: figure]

Evaluation Metric | Rough Value
Balancing Time (no perturbation)
Max Pitch (no perturbation)
Max Displacement in 1s (no perturbation)
Min Pitch to Drive Motors
Perturbation Reaction Time
Max Allowed Perturbation Pitch
Max Time to Restore from Pitch Perturbation
Max Displacement by Pitch Perturbation
Max Time to Restore from Yaw Perturbation of

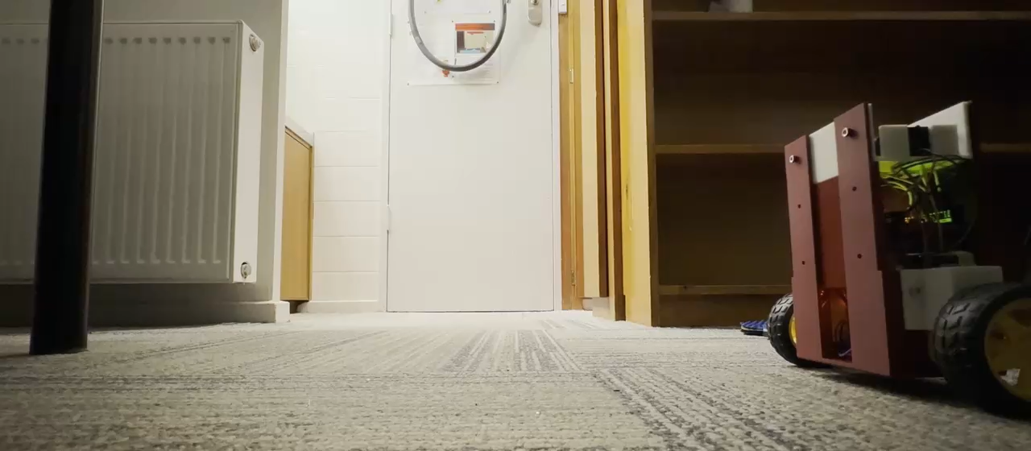
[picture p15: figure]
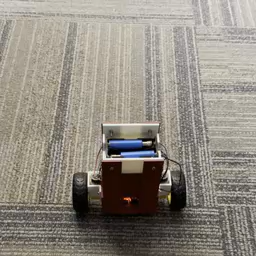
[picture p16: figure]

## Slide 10

Phase 1 (Week 7-8):

Phase 2 (Week 9-11):

Phase 3 (Week 12):

Improve the locking skill and motion skill

Develop the adaption skill and resurrection skill

Do the final improvements based on the tests

Project Management

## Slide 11

Thank you for listening!

References

[1] Wang, A., & Wang, A. (2026, January 27). Autonomous Mobile Robot (AMR) applications by industry. Fdata Robot. https://www.fdatabot.com/autonomous-mobile-robot-amr-applications-by-industry/

[2] Arvindpdmn, J. R. C. (2022, May 23). Mobile robot. Devopedia. https://devopedia.org/mobile-robot

[3] Quaternions. (n.d.). https://ece.montana.edu/seniordesign/archive/SP14/UnderwaterNavigation/Quaternions.html

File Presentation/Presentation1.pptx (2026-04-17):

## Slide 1


Design a Robot with Balancing Ability and Self-controllability

Team:
Members:

Box3
Zhihao Lin (u8175491@anu.edu.au)
Zongjun Yang (u8463895@anu.edu.au)

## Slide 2

Background


Types of robots [2]

Advanced requirements
- Fully control its state
- Follow a designated path
- Dynamically adapt to varying environments


Industry robots [1]

Requirements Review

Top-level requirements
- Maintain its balanced state
- Drift less than 0.5m in 1s
- Recover from 15° perturbation within 2s

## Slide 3

System Architecture

Arduino UNO
“The central processor”
- Clocking speed: 16 MHz
- Features: I2C, PWM


Li-ion cell
“The power supply”
- Capacity: 800 mAh
- Nominal voltage: 3.7 V

Electronic Components

MPU-6050 IMU
“The state sensor”
- Angular velocity res: 7.6×10^(−3) (^(∘) /s)
- Acceleration res: 61×10^(−6) g
- Features: I2C
- Communication speed: 400 kHz


L298N motor driver
“The action driver”
- Power output: 3.2 - 40 V
- Features: PWM


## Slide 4

Mechanical Design: Physical Model

L=1/2Mx^2 +1/2m[(x+lθcosθ)^2 +(lθsinθ)^2 ]−mglcosθ

Case 1: tiny perturbation ( θ≳0 , F=θ=0 )
θ≈((M+m)gsinθ)/(lM)
- We want θ to be as small as possible
- We need large l and small m

Use Lagrangian mechanics:

Case 2: dynamic equilibrium ( θ>0 , θ≈θ≈0 )
F_0 =(M+m)gtanθ
- We want θ to recover as soon as possible
- We need F>F_0

d/(dt)(∂L)/(∂x)−(∂L)/(∂x)=F

d/(dt)(∂L)/(∂θ)−(∂L)/(∂θ)=0

Case 3: severely unbalanced ( θ>0 , θ>0 )
- We want θ as negative as possible
- We need F≫F_0 and small l

θ=((M+m)gsinθ−Fcosθ)/((M+msin^2 θ)l)−(mθ^2 sin2θ)/(2(M+msin^2 θ))

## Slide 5

Mechanical Design: Chassis and Assemble


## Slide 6

Signal Processing: IMU

Sensor Fusion

Gyroscope
- Measure angular velocities ω
- Give yaw, pitch, and roll by integrating
- Cons: drift over time

Accelerometer
- Measure accelerations
- Determine pitch and roll from gravity direction
- Cons: noisy

Magnetometer
- Measure magnetic field
- Determine yaw from Earth’s magnetic field
- Cons: easily disturbed

Fusion
- Complementary Filter
- Mahony Filter
- …

- Represents the current state
- Shows the object has rotated around (q_1 ,q_2 ,q_3 ) by q_0
- More efficient and stable than Euler angles
- Update state: q[n+1]=q[n]+(Δt)/2⋅q[n]⊗ω

Quaternion

q=[q_0 ,q_1 ,q_2 ,q_3 ]

Quaternions

Quaternions [3]

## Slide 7

Signal Processing: PID Controller

Error term e(t): difference between the current state S(t) and the desired state s_0
Output u(t): used to drive the current state toward the desired state

F(t)∼u(t)=K_p e(t)+K_i ∫_0^t dτ e(τ)+K_d (de(t))/(dt)

the larger the error is, the large the output is to restore the state

the longer the error persists, the large the output is to further restore the state

the faster the error decreases, the smaller the output is to reduce oscillation

Proportional K_p e(t)
Integral K_i ∫_0^t dτe(τ)
Derivative K_d (de(t))/(dt)

Tune K_d

Tune s_0 and K_p

Tune and find better combination of (K_p ,K_i ,K_d )

Tune K_i

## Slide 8

Control Logic

Read States
- Calculate pitch, yaw, …
- Calculate acceleration in the world frame
- …

Check States
- Determine whether the pitch is recoverable
- Estimate the perturbation
- …

Feedback Control
- Calculate the output of PID controller
- Use other feedback logics
- …

Take Action
- Further adjust the controller output
- Control the motors
- …

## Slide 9

Current Progress


Evaluation Metric | Rough Value
Balancing Time (no perturbation) | ∼∞
Max Pitch (no perturbation) | ≈3.5^(∘)
Max Displacement in 1s (no perturbation) | ≈0.15 m
Min Pitch to Drive Motors | <0.4^(∘)
Perturbation Reaction Time | ≪0.2 s
Max Allowed Perturbation Pitch | ≈13^(∘)
Max Time to Restore from Pitch Perturbation | ≈1.5 s
Max Displacement by Pitch Perturbation | ≈1 m
Max Time to Restore from Yaw Perturbation of 180^(∘) | ≈3 s


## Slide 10

Project Management

Improve the locking skill and motion skill
Develop the adaption skill and resurrection skill
Do the final improvements based on the tests

Phase 1 (Week 7-8):
Phase 2 (Week 9-11):
Phase 3 (Week 12):

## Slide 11

Thank you for listening!

References

[1] Wang, A., & Wang, A. (2026, January 27). Autonomous Mobile Robot (AMR) applications by industry. Fdata Robot. https://www.fdatabot.com/autonomous-mobile-robot-amr-applications-by-industry/
[2] Arvindpdmn, J. R. C. (2022, May 23). Mobile robot. Devopedia. https://devopedia.org/mobile-robot
[3] Quaternions. (n.d.). https://ece.montana.edu/seniordesign/archive/SP14/UnderwaterNavigation/Quaternions.html

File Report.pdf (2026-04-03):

# Design a Robot with Balancing Ability and Self-controllability

# Zhihao Lin*

# 1 and Zongjun Yang†1

1Research School of Physics, Australian National University, Canberra ACT, 2601, Australia

# 1. EXECUTIVE SUMMARY / ABSTRACT

This report presents a comprehensive design review of an autonomous

two-wheeled self-balancing robot, including system architecture, phys-

ical modeling, and current prototype progress. The primary objective

is to develop a robot capable of maintaining dynamic balance, resisting

external perturbations, and executing controlled motion.

The proposed system architecture is driven by an Arduino UNO

with a high-frequency Proportional-Integral-Derivative (PID) feed-

back control. Real-time spatial states sensing is acquired via an I

2C

MPU-6050 IMU. Actuation is delivered by two geared DC motors

controlled by an L298N motor driver. Furthermore, the 3D-printed

physical chassis was modeled using Lagrangian mechanics, intention-

ally increasing the height of mass center to lower the falling speed

and provide the processor a temporal window for actuation.

As of Week 6, the project is progressing ahead of schedule. The

physical prototype has been fully assembled, and the core balancing

functionality has been successfully demonstrated. The robot can main-

tain steady-state equilibrium indefinitely with minimal drift (< 0.15m

in 1s). While the current hardware configuration recovers from dis-

turbances up to only 13◦

(less than the 15◦
target), the direction of

mechanical and control improvements have been identified to resolve

this during the next phase.

Moving forward, the team has transitioned to a concurrent engi-

neering approach to develop advanced mobility and adaption skills in

parallel. A revised timeline is used to map the final integration and

comprehensive testing phases across Weeks 7-12.

# 2. INTRODUCTION

# 2.1. Background

There are increasing applications that need robots to participate. For

example, complicated transportation in lab environments [1], security

support with interaction ability [2], and educational communication

[3]. With the revolution of machine learning and artificial intelli-

gence, robots are becoming much more intelligent [4, 5], which will

be applied to wider field.

Fundamentally, a robot requires several characteristics including:

it must be produced by manufacture, it must be able to move itself or

other objects, and it must be able to respond to its environment [6].

This indicates the essential parts of a robot: physical bodies, action

drivers, sensors, and processors (controllers). Mobile robot is a typical

case of both robot definition and robot applications [5, 7].

To implement robots to everyday applications, we need to start from

a prototype, and upgrade it step by step. The objective of this project is

to design, fabricate, and program an autonomous robot with excellent

balancing performance and high controllability.

# 2.2. Requirements Review

The primary objective of this project is to build an autonomous self-

balancing robot which is able to move to or keep itself around a desig-

nated position. To achieve this, the listed specific requirements are as

follows:

- Top-level requirements:

– The robot must maintain its balanced position without any

falling cases.

*u8175491@anu.edu.au

†u8463895@anu.edu.au

– If the robot is perturbed externally (e.g., a deliberated push,

or an obstacle collided), it must be able to return balanced

within 2s. The perturbation is defined as changing its pitch

angle up to 15◦

– Without perturbation, the robot must balance itself in a

small range. It must not move more than 0.5m in 1s.

- Electronic components:

– The robot must be able to sense its angle or velocity at >

100Hz. The resolution of angle must be < 0.5

◦

– The robot must take action within 0.1s after a controlling

signal is sent.

– The electronics must be stable during its runtime.

– After turning on, the robot must work entirely indepen-

dently, including power supply, signal processing, and con-

trolling.

- Physical structure:

– The structure must be stable enough that the position of

mass center doesn’t change.

– The chassis must be sturdy, which can resist damage when

the robot falls in some cases.

- Advanced requirements:

– The robot can be able to fully control its state, including

facing direction and moving speed.

– The robot can follow a designated path without obvious
drift.

– The robot can dynamically adapt its response to varying

operational environments: in peaceful environments, being

slightly perturbed, being strongly perturbed, commanded

to move to and keep around a position.

# 3. TECHNICAL DETAILS AND ANALYSIS

# 3.1. System Architecture

Fig. 1 shows the flowchart of the basic balancing idea of the robot.

Generally, it shows the realization of the basic balancing skills. Any

other advanced skills can be add to these parts. Reading multiple

types of states (e.g., pitch angle, yaw angle, and x-acceleration) can be

add in the "Read State" process. "Check States" decision can be used

to assess the situation of the robot. "Feedback Controller" process can

handle different controllers, such as PID controller. "Take Action"

process controls the states of the robot.

## Start

## End

## Read States

## Feedback

Control | Take Action

## Check States

Unbalanceable

Normal

Figure 1. Flowchart of basic balancing logic. After turning on, the robot keeps

reading its state, such as the pitch angle or the angular velocity of y-axis. If it’s

not strongly unbalanced, feedback controllers are used to generate an output

from the state. The output is used to control the robot, such as moving

forward or turn left. The feedback loop can balance the robot theoretically.

We started from developing the basic balancing skill. When this first

stage was completed successfully, we would try to realize the advanced

requirements by upgrading the existed processes or decisions instead

of rebuild a new structure. In this way, the development would be

controllable and the progress would be clear. However, a new structure

can be required if we want to develop a more complex logic.

1

# 3.2. Electronic Components

To achieve the main goal, the electronic components should contain

these necessary parts: a state sensor, a central processor, an action

driver, and power supply.

## 3.2.1. The state sensor

We use MPU-6050 inertial measurement unit (IMU) as the state sensor.

It consists of a triple-axis gyroscope and a triple-axis accelerometer.

Using the angular velocities and linear accelerations, we can get or

calculate most of the important states of robot. The key parameters of

### MPU-6050 are listed in Table 1:

Parameter | Value | Unit
Gyroscope Full-scale Range | ±250 | ◦∕s
Gyroscope Sensitivity | 131 | LSB∕(◦∕s)
Gyroscope Noise Spectral Density | 0.005 | ◦∕s∕

√
| | Hz
Gyroscope Output Rate | 8000 | Hz
Accelerometer Full-scale Range | ±2 | g
Accelerometer Sensitivity | 16384 | LSB∕g
Accelerometer Noise Spectral Density | 400 | μg∕

√
| | Hz
Accelerometer Output Rate | 1000 | Hz
Supported Communication | I 2C
Communication Speed | 400 | kHz
Clocking Speed | 32.768k ∼ 19.2M | Hz
Power Input Voltage | 2.375 ∼ 3.46 | V

Table 1. The key parameters of MPU-6050 inertial measurement unit [8]

The best resolution of angular velocity can reach 7.6×10⁻³ ◦∕s, and

the best resolution of acceleration can reach 61 × 10⁻⁶ g. Ignoring

the noise, these resolutions are totally sufficient for the requirements.

Both the sampling rate and communication speed satisfy our require-

ments. The primary limitation of this IMU is the inherent sensor noise

or drift. Considering the noise, we can try to process the signal (such

as low-pass filter or quaternion) to get high enough resolution.

## 3.2.2. The central processor

Arduino UNO is chosen as the processor. We can use it to get data

from the IMU, process the data, and control the action driver. Its key

parameters are listed in Table 2:

Parameter | Value | Unit
# Digital I/O Pins | 14

# Analog Input Pins | 6

# PWM Pins | 6

Supported Communication | I
| 2C, SPI, UART
Clocking Speed | 16 | MHz
Power Output Voltage | 3.3, 5 | V
Power Input Voltage | 7 ∼ 12 | V

Table 2. The key parameters of Arduino UNO [9]

The number of digital, analog and PWM pins are enough for the

wiring connecting the processor to the sensor and the action driver.

The high processing speed is ideal for our control logic. Using I

2C

communication and 3V3 output power, it can match the MPU-6050

very well. However, the power output voltage may not be enough for

some action drivers. So a shared power supply may be required.

## 3.2.3. The action driver

We choose to use a L298N motor driver and two geared DC motors.

The key parameters of the L298N motor driver are listed in Table 3:

Parameter | Value | Unit
Digital Input Pins | IN1 + IN2, IN3 + IN4
PWM Input Pins | ENA, ENB
Logic Input Voltage | 5 | V
Power Output Voltage | 3.2 ∼ 40 | V
Power Input Voltage | 5 ∼ 35 | V

Table 3. The key parameters of L298N motor driver [10]

The motor driver allows PWM input, which matches well with

the Arduino UNO. The digital input pins can be used to control the

direction of motors, while the PWM input pins can be used to control

the speed. The required voltage is high as expected, so a good power

supply is needed. However, by experiments, we found that the motors

can keep still when the speed signal is small, which is caused by the

internal static friction. Feed-forward controller can be added to solve

this dead-band. Moreover, the two motors have a little asymmetry,

which makes the robot yaw. Therefore, stepper motors can be required

when we need to do precise control or measurement.

## 3.2.4. Power supply

We need to supply power to both the Arduino UNO and the motor

driver. Therefore, two 800mAh 3.7V rechargeable Li-ion cells are

used. For reusability, we use a breadboard to transfer the power from

batteries to the two components instead of soldering the wires. The

safe charged voltage of Li-ion is 2.8 ∼ 4.2 V. By testing, the batteries

need to be recharged after working for about 10 hours.

## 3.2.5. Wiring structure

As mentioned above, the electronic components used are:

### - MPU-6050 IMU

- Arduino UNO
- L298N motor driver
- Geared DC motors
- Li-ion Batteries
- Breadboard

The wiring method is shown in Fig. 2.

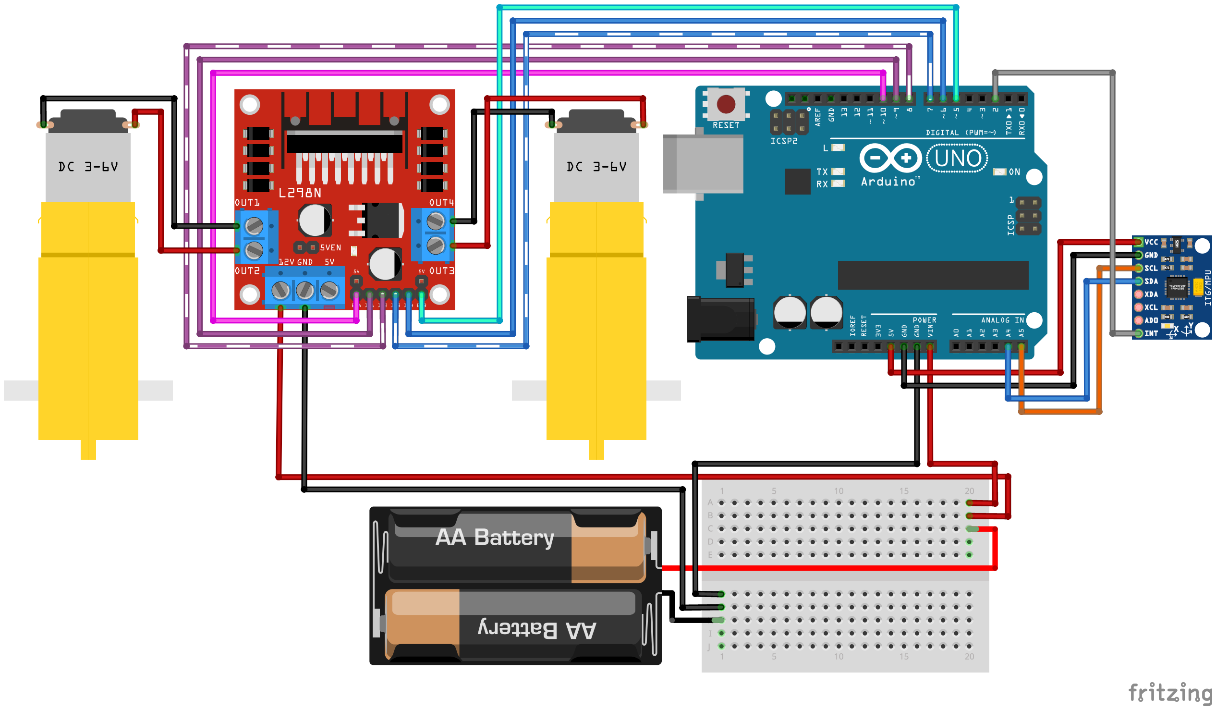
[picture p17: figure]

Figure 2. Wiring diagram of the electronic components. The battery and

breadboard are used to power the Arduino UNO and L298N motor driver.

UNO communicates with MPU-6050 inertial measurement unit (IMU) using

I2C protocol, and sends analog signal to the motor driver using pulse width

modulation (PWM). The motor driver controls 2 motors.

# 3.3. Mechanical Design

## 3.3.1. Physical model analysis

Fig. 3 shows the simplified physical model of the robot. We can use

Lagrangian mechanics to analyze the relationship between F and θ, x.

2

The system Lagrangian and Euler–Lagrange equations are given by:

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
## (ẋ + lθ̇ cos θ)

## 2 + (lθ̇ sin θ)

2

]

## − mgl cos θ (1)

d

dt

∂L

∂ẋ

−

∂L
∂x = F | ⇐⇒ | (M + m)ẍ + mlθ̈ cos θ − mlθ̇ ² | sin θ = F

(2)

d

dt

∂L

∂θ̇

−

∂L
∂θ = 0 | ⇐⇒ | ẍ cos θ + lθ̈ − g sin θ = 0 | (3)
M | F

θ

| m

g

x

l

Figure 3. A simplified physical model of the robot. Constrain the movement

in 1 dimension. THe model consists of a wheel with mass M, a body mass

center m, and a light stick connecting these two with length l. The action of

wheel is simplified as a force F. Assume the robot is at position x and its pitch

angle is θ.

Usually, we care about the dynamic of θ, which can be derived from

Equation 2 and Equation 3:

θ̈ =

## (M + m)g sin θ − F cos θ

## (M + m sin²

θ)l

−

## mθ̇ ² sin 2θ

## 2(M + m sin²

θ)

(4)

According to the model Fig. 3 and this Equation 4, we can analyze

some cases:

- The robot is perfectly at the balanced state, but a perturbation happens before the controller realizes it (i.e., θ ⪆ 0, F = θ̇ =

0). In this case, θ̈ ≈

(M+m)g sin θ

lM

. To maximize the controller’s

temporal response window before θ reaches an unbalanceable angle, we want θ̈ to be as small as possible, which means we need

to use small m and/or large l.
- The robot is in a state of dynamic equilibrium (i.e., θ > 0, θ̈ ≈

θ̇ ≈ 0). To keep a constant θ, it’s necessary to make F = (M +

m)g tan θ. However, because of the limit of motor power, F can

be maintained for only a short time before the large speed brings

large resistance. So we should make F > (M + m)g tan θ to bring

back balance before the saturation of motors.
- The robot is severely unbalanced (i.e., θ > 0, θ >̇ | 0). In this

case, the only possible way to balance the robot is to make θ̈ as

negative as possible (i.e., θ ≪̈ 0). To achieve this, we need to use

a combination of large F > (M + m)g tan θ and small l.

- The robot is inverted (i.e., 90◦ < θ < 270◦

## (l < Rwheel), l = 0, or

m = 0). Now the robot is impossible to return to the desired bal-

anced state (or the balanced state can’t be defined), but becomes

permanently stable.

In conclusion, a motor being able to produce huge F is wanted for all the cases. Similarly, it’s good to have small m, M, and/or m

M

. Large l

is suitable for peaceful environment and high balance performance,

while small l or inverted robot is suitable for severe environment and

high controllability.

## 3.3.2. Chassis

We use CAD (Autodesk Fusion) to design the chassis model, and 3D-

print the model. The chassis is designed with many components in

the experimental stage to make some components easier to update.

These components are assembled using M3 bolts and nuts. For the

final design, all the components are combined into a whole one to

make the chassis stable.

In Fusion, the chassis is designed with the help of the models of

other electronic components. Official datasheets of the electronic

components are also used. In this way, it’s precise and accurate to

design the size and position of chassis components and through holes.

One of our CAD model designs is shown in Fig. 4. It has high mass

center, which can perform good balancing skill but lack flexibility.

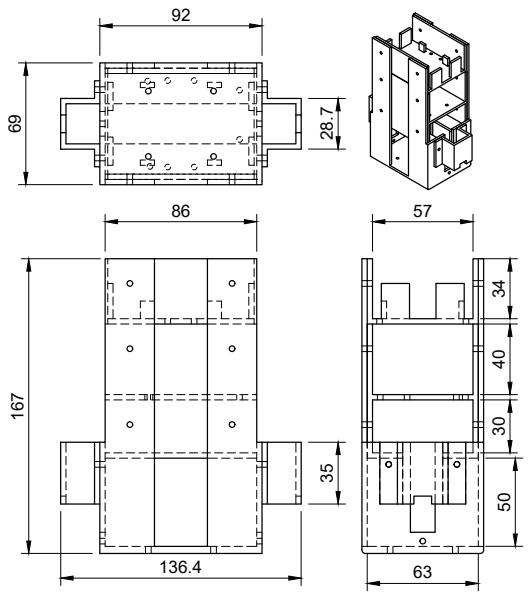
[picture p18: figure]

(a) Front-top-side view

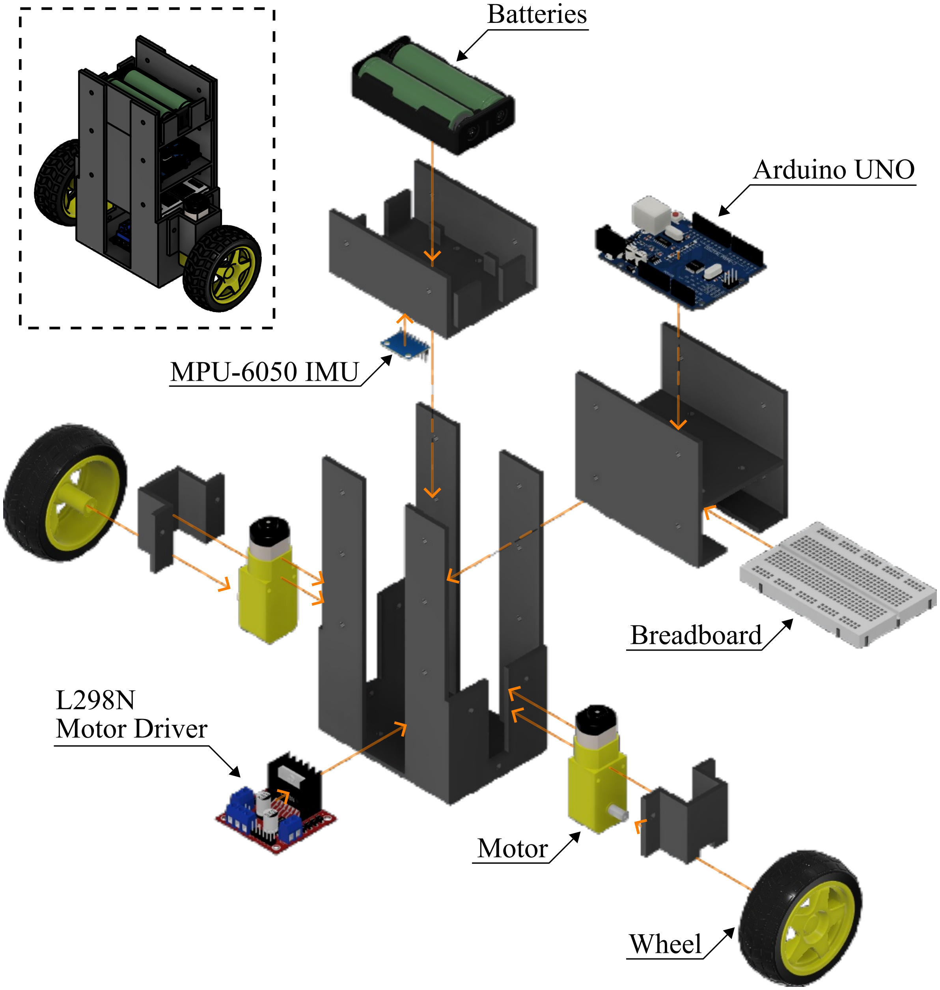
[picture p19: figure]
Batteries; Arduino UNO; Breadboard; L298N Motor Driver; MPU-6050 IMU; Motor; Wheel

(b) Robot components and assembly

Figure 4. A chassis model design.

PrusaSlicer is used to convert CAD models to 3D-printing code.

The printer uses PLA as the filament with diameter of 1.75mm. To

make our chassis sturdy, we use layer height of 0.3mm. The vertical

shells is set to 4 perimeters, and the horizontal shells is set to 4 top

3

layers and 4 bottom layers. Since most of our chassis consist of plates

of 3mm, these parameters are sufficient to make our chassis solid. The

fill density is set to 15%. The only disadvantage is that solid chassis

may increase the mass. We compensated it by change the height of

mass center by a larger value.

# 3.4. Signal Processing

## 3.4.1. IMU data processing

To get the robot state, we need to process the data from the IMU. The

IMU contains a 3-axis gyroscope used to measure angular velocity and

a 3-axis accelerometer used to measure acceleration. One important

thing we can do is to get the angle (yaw, pitch, roll) from these values.

Simply, we can integrate the 3 angular velocities (ωx

, ωy

, ωz

) to get

the corresponding Euler angle. However, Euler angles suffer from

Gimbal Lock, resulting in the loss of a degree of freedom and causing

ambiguous calculations (for example, the results are the same whether

it yaws by 30◦

and then pitches by 90◦

, or pitches by 90◦
and then rolls
by 30◦
, which makes it difficult to determine the true yaw or roll angle).

Because of this, we use quaternion q = (q0

, q1

, q2

, q3

) to represent the

angle state, which indicates the current state that is equivalent to

rotate the initial state around an axis (q1

, q2

, q3

) by an amount of q0

The current quaternion is given by:

qn = qn−1 +

∆t

2

⋅ qn−1 ⊗ ω | (5)

Another method to get quaternion is using the accelerations
(ax

, ay

, az

). Because there is a constant gravity of ≈ 9.8m ⋅s

−2, we can

know the quaternion by comparing the direction of measured accel-

eration with the true gravity. However, this method is noisy, while

using gyroscope can produce drift over a long time. We can mitigate

the high-frequency noise of accelerometers by a low-pass filter, and

the low-frequency drift of gyroscopes by a high-pass filter, which is

called complementary filter.

There are many states we can calculate from the quaternion (Most

calculations can be done by the IMU module or some libraries such

## as i2cdevlib/Arduino/MPU6050). For example:

## Pitch: θ = arcsin (2(q0q2 − q3q1

)) | (6)

## Yaw: ψ = arctan

# 2(q0q3 + q1q2

)

1 − 2(q

2
2 + q
2/3) | (7)

Acceleration: aworld = q ⊗ (0, ax

, ay

, az

) ⊗ q⁻¹ | (8)

In this way, we can get the tilt angles or accelerations much more

precisely and unambiguously. However, to get the displacement of

the robot, we need to integrate the acceleration twice, which can

brings huge noise and drift. This disadvantage is mostly caused by the

hardware, which is hard to improve by software. Therefore, we can

choose to calculate the displacement from the signal used to control

the speed of motors.

## 3.4.2. PID controller

PID (Proportional-Integral-Derivative) controller is the core of the

feedback system. By comparing the current state S(t) with the desired

state, we get an error term e(t). Using e(t) as the input of PID con-

troller, we can use the output u(t) to drive the current state toward

the desired state. The output expression is given by:

## u(t) = Kpe(t) + Ki ∫

t

0

## dτ e(τ) + Kd

## de(t)

dt | (9)

The Proportional term means that the larger the error is, the large

the output is to restore the state. The Integral term means that the

longer the error persists, the large the output is to further restore the

state. The Derivative term means that the faster the error decreases, the smaller the output is to reduce oscillation. The three terms have

individual coefficients (Kp

, Ki

, Kd
). Their combinations vary widely

across different situations.

For the PID of balancing pitch angle, the 3 coefficients need to

be tune along with the balanced pitch angle θ0
. First, we found the

approximate pitch angle. Based on this, we adjusted only θ0 and Kp

until the robots fell in both directions with a similar low probability,

which means θ0
is closed to the true balanced pitch angle. Then, we

tuned Kd
such that the robot wouldn’t oscillate too much around the
θ0
. However, the robot may occasionally keep moving in one direction.

We used large Ki
to correct it. The optimal tuning yields highly varied

## coefficients. For example, Kp = 48, Ki = 600, and Kd = 0.19 with PID

sample time = 2ms. By tunning these coefficients and looking for a

good balancing state, we can achieve better feedback performance.

## 3.4.3. Pulse width modulation

In order to control the robot smoothly and continuously, we need

analog signals to do the task. However, the UNO has only digital

output, which means the output voltage can be either HIGH level

or LOW level without any values in between. PWM can solve this

problem. Instead of encoding signals to voltage level, it produces

a train of pulses as the output, and encodes signals to the width of

each pulse. Meanwhile, our motor driver is able to receive the PWM

signals.

However, the range of PWM values is limited. This disadvantage

can be ignored in our cases, since the resolution of PWM is much

better than the resolution of geared motors.

# 3.5. Control Logic

The program for controlling runs in Arduino UNO. The structure of

control logic is based on 3.1 and Fig. 1, whose details are shown below:

## 3.5.1. Start

In this initialization sequence, all the components are configured. If

anyone of them is not initialized successfully, the following controlling

code would not run.

- initImu(): Sets the offsets of 3 axises for the gyroscope and the

accelerometer, and waits until the IMU becomes stable.

- initPID(): Defines the balanced pitch and yaw, the PID coeffi-

cients for different situations, and the PID object for pitch and

yaw.

## - initMotor(): Uses pinMode(pin, mode) to initialize 2 EN pins

and 4 IN pins.

## 3.5.2. Read States

In this process, we get the states of the robot from the calculations

about quaternion. The logical code is shown in Code 1 For pitch and

yaw angles, we calculate the error between the true angle and the

balanced angle, unwrap the 2π period, and use the result as the input

of feedback control. For accelerations, we compute the value in the

world frame using the quaternion.

## double unwrapAngle(float angle, double balanced) {

double a = angle * 180 / M_PI - balanced;
// ... unwrap from 2*pi ...
}

## bool getRobotState() {

imu.dmpGetQuaternion(&quaternion, imuFifoBuffer); imu.dmpGetYawPitchRoll(imuYpr, &quaternion, &gravity); pitchAngle = unwrapAngle(imuYpr[1], balancedPitch); // ... doing similar jobs for yaw and acceleration ... imu.dmpGetLinearAccelInWorld(...);
}

Code 1. Example code of "Read States" process

4

## 3.5.3. Check States

The states gotten from the previous process is analyzed, and the next

step is determined. For example (as shown in Code 2), the coefficients

of PID controller will dynamically transition to surviving mode (high-

gain feedback) if the pitch angle is too large, or the motors will be

disabled if the robot is destined to fall.

## if (abs(pitchAngle) > maxPitchAngle) { motorStop(); }

// ...

## if (abs(pitchAngle) > survivingPitch) {

pitchPID.SetTunings(sKp, sKi, sKd);

## } else { pitchPID.SetTunings(kp, ki, kd); }

Code 2. Example code of "Check States" process

## 3.5.4. Feedback Control

Our feedback control is currently based on only PID controller. We

use a library to manage the computing. In the code, the feedback

output can be gotten from pid.Compute(). The code is simple, while

this process is essential to the robot. All the coefficients need plenty

of time to tune manually.

## 3.5.5. Take Action

This process convert the digital signals from feedback control into a

real action of the robots. For example, accelerating immediately, or

rotating clockwise slowly. The action is also influenced by "Check

States". As shown in Code 3, balancing the pitch is a priority over

adjusting the yaw.

## if (abs(motorValue) > maxMotorValue * 0.3) {

motorMove(motorValue, ENA_PIN, IN1_PIN, IN2_PIN); motorMove(motorValue, ENB_PIN, IN3_PIN, IN4_PIN);

## } else {

motorMove(motorValue + yawCorrection, ENA_PIN, ...); motorMove(motorValue - yawCorrection, ENB_PIN, ...); }

Code 3. Example code of "Take Action" process

# 4. PROTOTYPE PROGRESS

# 4.1. Current Prototype Capabilities

During the last 6 weeks, we have finished these tasks: connecting and

initializing each components, reading angles and accelerations from

IMU, using PWM to driver motors, balancing the robot by its pitch

angle with PID, controlling the yaw angle basically.

The robot of current version is shown in Fig. 5.

Preliminary performance metrics of the current prototype are listed

in Table 4. Most top-level requirements mentioned in 2.2 are achieved.

Some evaluations are even better than expected, such as the max

displacement in 1s without perturbation. However, the max allowed

perturbation pitch (< 15◦
) is not achieved. It’s because the high mass

center can weaken its perturbation resistance. To improve this skills,

we will try to increase the strength of motor driver, increase the wheel

size, or decease the mass and the height of mass center.

# 4.2. Current State

It’s the 6th week. We are mainly focusing on the reports and the review

of the last 6 weeks. Meanwhile, we also start to design or improve

the prototype to achieve the advanced requirements. These tasks

are being done: controlling the yaw angle with high flexibility, and

controlling the linear motion at a constant speed with good balance

performance.

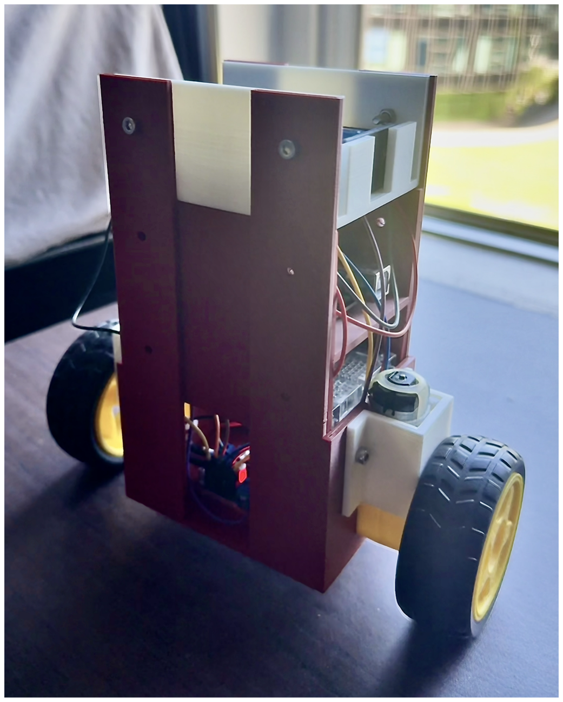
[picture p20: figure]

Figure 5. The robot with complete basic balancing skills and preliminary

advanced skills. It can stably balance itself on a small table.

Evaluation Metric | Rough Value
Balancing Time (no perturbation) | ∼ ∞
Max Pitch (no perturbation) | ≈ 3.5 ◦
Max Displacement in 1s (no perturbation) | ≈ 0.15 m
Min Pitch to Drive Motors | < 0.4 ◦
Perturbation Reaction Time | ≪ 0.2 s
Max Allowed Perturbation Pitch | ≈ 13◦
Max Time to Restore from Pitch Perturbation | ≈ 1.5 s
Max Displacement by Pitch Perturbation | ≈ 1 m
Max Time to Restore from Yaw Perturbation of 180◦ | ≈ 3 s

Table 4. Some key evaluations of the robot of current version.

# 5. PROJECT MANAGEMENT

# 5.1. Responsibilities

Initially, the project was divided into two parts: hardware and software.

The origin responsibilities are listed below:

- Lin: hardware part, including electronic components and me-

chanical design

- Yang: software part, including signal processing and control logic

However, our progress was unexpectedly fast. The first version of

balancing robot was developed much earlier than planned. After

discussions, we both agreed that designing the hardware and software

together is much more efficient than designing them individually

and then combining them. By team working and peer learning, we

quickly mastered both the hardware and software part. Therefore, we

use a semi-parallel structure for our project. Both of us is responsible

to design a robot with different skills individually while sharing the

same mechanical and logical architecture. There are also regular

discussions about integrating these skills into one robot. Our current

responsibilities about skill designing are listed below:

- Lin:

– Locking skill: the robot can lock itself to a certain direction,

even if it’s rotated by us deliberately.

– Adaption skill: the robot can judge the situation that it’s

facing or will face.

- Yang:

– Motion skill: the robot can move forward and backward

actively while keeping balanced.

– Resurrection skill: the robot can restore itself from a heavy

perturbation.

Combining these skills, we can achieve the advanced requirements

mentioned in 2.2

5

# 5.2. Estimated Timeline

The remaining development will be divided into 3 phases:

- Phase 1: Improve the locking skill and motion skill. Combine

them into one robot.

- Phase 2: Develop the adaption skill and resurrection skill. Dis-

cuss the development plans in the beginning, and combine the

development results at the end.

- Phase 3: Conduct comprehensive tests. Do the final improve-

ments based on the performance.

The detailed timeline is shown in Fig. 6

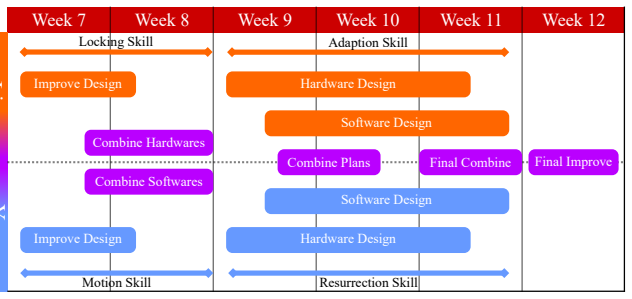
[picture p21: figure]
Improve Design; Hardware Design; Software Design; Combine Hardwares; Combine Softwares; Locking Skill; Motion Skill; Resurrection Skill; Adaption Skill

Week 7 | Week 8 | Week 9 | Week 10 | Week 11 | Week 12

# Lin Yang

Combine Plans | Final Combine | Final Improve

Figure 6. The Gantt chart of our estimated timeline.

# 5.3. Budget

This project has light budget requirements. The robot is assembled

using off-the-shelf components and programmed using free and open-

source libraries. A copy of the parts was provided to us, but they can

be acquired online for about $130 AUD. The cost of 3D printing the

prototype chassis was less than 5 AUD.

# 6. CONCLUSION

This design review has detailed system architecture, mathematical and

physical foundations, and developmental progress of an autonomous

balancing robot. By leveraging a Lagrangian dynamic model, the phys-

ical chassis was currently optimized with an elevated center of mass.

System requirements have been addressed through a robust electron-

ics stack, utilizing an I

### 2C MPU-6050 IMU. A 500 Hz PID control loop

effectively translates error calculations into physical restoration via

the L298N motor drivers. Current prototype testing confirms the vi-

ability of this design; the robot successfully maintains steady-state

dynamic equilibrium with minimal drift and recovers from impulse

perturbations up to 13◦

While the current perturbation resistance falls marginally short

## of the 15◦

target, the identified hardware limitations provide a clear

pathway for refinement. As the project enters the final phases of

development, the transition to a concurrent engineering strategy en-

sures that advanced mobility and adaptation skills will be integrated

efficiently.

# REFERENCES

[1] H. Liu, N. Stoll, S. Junginger, and K. Thurow, “A fast method

for mobile robot transportation in life science automation,”

## in 2013 IEEE International Instrumentation and Measurement

Technology Conference (I2MTC), 2013, pp. 238–242. doi: 10.

### 1109/I2MTC.2013.6555416. (https://doi.org/10.1109/I2MTC.2013.6555416)

[2] A. Lopez, R. Paredes, D. Quiroz, G. Trovato, and F. Cuellar,

“Robotman: A security robot for human-robot interaction,”

## in 2017 18th International Conference on Advanced Robotics

(ICAR), 2017, pp. 7–12. doi: 10.1109/ICAR.2017.8023489. (https://doi.org/10.1109/ICAR.2017.8023489)

[3] T. Belpaeme, J. Kennedy, A. Ramachandran, B. Scassellati,

and F. Tanaka, “Social robots for education: A review,” Science

Robotics, vol. 3, no. 21, eaat5954, 2018. doi: 10.1126/scirobotics.

### aat5954. (https://doi.org/10.1126/scirobotics.aat5954)

[4] M. Soori, B. Arezoo, and R. Dastres, “Artificial intelligence,

machine learning and deep learning in advanced robotics, a

### review,” Cognitive Robotics, vol. 3, pp. 54–70, 2023, issn: 2667-

2413. doi: https://doi.org/10.1016/j.cogr.2023.04.001. (https://doi.org/https://doi.org/10.1016/j.cogr.2023.04.001)

[5] R. Raj and A. Kos, “A comprehensive study of mobile robot: His-

tory, developments, applications, and future research perspec-

tives,” Applied Sciences, vol. 12, no. 14, 2022, issn: 2076-3417.

### doi: 10.3390/app12146951. (https://doi.org/10.3390/app12146951)

## [6] D. J. Todd, Fundamentals of robot technology: An introduction to industrial robots, teleoperators and robot vehicles. Springer

Science & Business Media, 2012.

[7] S. G. Tzafestas, “Mobile robot control and navigation: A global
overview,” Journal of Intelligent & Robotic Systems, vol. 91, no. 1,

### pp. 35–58, 2018, issn: 1573-0409. doi: 10.1007/s10846- 018-

### 0805-9. (https://doi.org/10.1007/s10846-018-0805-9)

## [8] InvenSense, Inc., Mpu-6000 and mpu-6050 product specifica-

### tion, PS-MPU-6000A-00, version 3.4, Accessed: 2026-04-01, In-

venSense (TDK Group), Aug. 2013. [Online]. Available: https:

//invensense.tdk.com/wp-content/uploads/2015/02/MPU-

6000-Datasheet1.pdf. (https://invensense.tdk.com/wp-content/uploads/2015/02/MPU-6000-Datasheet1.pdf)

[9] Arduino. “Arduino uno rev3.” Accessed: 2026-04-01. [Online].

Available: https://docs.arduino.cc/hardware/uno-rev3/.

## [10] Handson Technology, L298n motor driver module datasheet, Ac-

cessed: 2026-04-01, Handson Technology, n.d. [Online]. Avail-

able: https : / / www. handsontec . com / dataspecs / L298N %

20Motor%20Driver.pdf. (https://www.handsontec.com/dataspecs/L298N%20Motor%20Driver.pdf)

6

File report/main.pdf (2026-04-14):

# Design a Robot with Balancing Ability and Self-controllability

Zhihao Lin*

1 and Zongjun Yang†1

1Research School of Physics, Australian National University, Canberra ACT, 2601, Australia

### 1. EXECUTIVE SUMMARY / ABSTRACT

This report presents a comprehensive design review of an autonomous two-wheeled self-balancing robot, including system architecture, physical modeling, and current prototype progress. The primary objective is to develop a robot capable of maintaining dynamic balance, resisting external perturbations, and executing controlled motion.
The proposed system architecture is driven by an Arduino UNO with a high-frequency Proportional-Integral-Derivative (PID) feedback control. Real-time spatial states sensing is acquired via an I

2C
MPU-6050 IMU. Actuation is delivered by two geared DC motors controlled by an L298N motor driver. Furthermore, the 3D-printed physical chassis was modeled using Lagrangian mechanics, intentionally increasing the height of mass center to lower the falling speed and provide the processor a temporal window for actuation.
As of Week 6, the project is progressing ahead of schedule. The physical prototype has been fully assembled, and the core balancing functionality has been successfully demonstrated. The robot can maintain steady-state equilibrium indefinitely with minimal drift (< 0.15m in 1s). While the current hardware configuration recovers from disturbances up to only 13◦

(less than the 15◦
target), the direction of
mechanical and control improvements have been identified to resolve this during the next phase.
Moving forward, the team has transitioned to a concurrent engineering approach to develop advanced mobility and adaption skills in parallel. A revised timeline is used to map the final integration and comprehensive testing phases across Weeks 7-12.

### 2. INTRODUCTION

### 2.1. Background

There are increasing applications that need robots to participate. For example, complicated transportation in lab environments [application_lab_transportation_liu_2013], security support with interaction ability [application_security_lopez_2017], and educational communication [application_social_tony_2018]. With the revolution of machine learning and artificial intelligence, robots are becoming much more intelligent [ai_soori_2023, mobile_robot_raj_2022], which will be applied to wider field. Fundamentally, a robot requires several characteristics including: it must be produced by manufacture, it must be able to move itself or other objects, and it must be able to respond to its environment [fundamental_todd_2012]. This indicates the essential parts of a robot: physical bodies, action drivers, sensors, and processors (controllers). Mobile robot is a typical case of both robot definition and robot applications [mobile_robot_tzafestas_2018, mobile_robot_raj_2022].
To implement robots to everyday applications, we need to start from a prototype, and upgrade it step by step. The objective of this project is to design, fabricate, and program an autonomous robot with excellent balancing performance and high controllability.

### 2.2. Requirements Review

The primary objective of this project is to build an autonomous self-balancing robot which is able to move to or keep itself around a designated position. To achieve this, the listed specific requirements are as follows:

- Top-level requirements:

*u8175491@anu.edu.au
†u8463895@anu.edu.au

– The robot must maintain its balanced position without any falling cases.
– If the robot is perturbed externally (e.g., a deliberated push, or an obstacle collided), it must be able to return balanced within 2s. The perturbation is defined as changing its pitch angle up to 15◦
– Without perturbation, the robot must balance itself in a small range. It must not move more than 0.5m in 1s.
- Electronic components:

– The robot must be able to sense its angle or velocity at > 100Hz. The resolution of angle must be < 0.5

◦
– The robot must take action within 0.1s after a controlling signal is sent.
– The electronics must be stable during its runtime.
– After turning on, the robot must work entirely independently, including power supply, signal processing, and controlling.
- Physical structure:

– The structure must be stable enough that the position of mass center doesn’t change.
– The chassis must be sturdy, which can resist damage when the robot falls in some cases.
- Advanced requirements:

– The robot can be able to fully control its state, including facing direction and moving speed.
– The robot can follow a designated path without obvious drift.
– The robot can dynamically adapt its response to varying operational environments: in peaceful environments, being slightly perturbed, being strongly perturbed, commanded to move to and keep around a position.

### 3. TECHNICAL DETAILS AND ANALYSIS

### 3.1. System Architecture

Fig. 1 shows the flowchart of the basic balancing idea of the robot. Generally, it shows the realization of the basic balancing skills. Any other advanced skills can be add to these parts. Reading multiple types of states (e.g., pitch angle, yaw angle, and x-acceleration) can be add in the "Read State" process. "Check States" decision can be used to assess the situation of the robot. "Feedback Controller" process can handle different controllers, such as PID controller. "Take Action" process controls the states of the robot.

Start

End

Read
States

Feedback
Control | Take Action

Check
States

Unbalanceable

Normal

Figure 1. Flowchart of basic balancing logic. After turning on, the robot keeps reading its state, such as the pitch angle or the angular velocity of y-axis. If it’s not strongly unbalanced, feedback controllers are used to generate an output from the state. The output is used to control the robot, such as moving forward or turn left. The feedback loop can balance the robot theoretically.

We started from developing the basic balancing skill. When this first stage was completed successfully, we would try to realize the advanced requirements by upgrading the existed processes or decisions instead of rebuild a new structure. In this way, the development would be

1

controllable and the progress would be clear. However, a new structure can be required if we want to develop a more complex logic.

### 3.2. Electronic Components

To achieve the main goal, the electronic components should contain these necessary parts: a state sensor, a central processor, an action driver, and power supply.

### 3.2.1. The state sensor

We use MPU-6050 inertial measurement unit (IMU) as the state sensor. It consists of a triple-axis gyroscope and a triple-axis accelerometer. Using the angular velocities and linear accelerations, we can get or calculate most of the important states of robot. The key parameters of MPU-6050 are listed in Table 1:

Parameter | Value | Unit
Gyroscope Full-scale Range | ±250 | ◦∕s
Gyroscope Sensitivity | 131 | LSB∕(◦∕s)
Gyroscope Noise Spectral Density | 0.005 | ◦∕s∕

√
Hz
Gyroscope Output Rate | 8000 | Hz
Accelerometer Full-scale Range | ±2 | g
Accelerometer Sensitivity | 16384 | LSB∕g
Accelerometer Noise Spectral Density | 400 | μg∕

√
Hz
Accelerometer Output Rate | 1000 | Hz
Supported Communication | I

2C
Communication Speed | 400 | kHz
Clocking Speed | 32.768k ∼ 19.2M | Hz
Power Input Voltage | 2.375 ∼ 3.46 | V

Table 1. The key parameters of MPU-6050 inertial measurement unit [mpu6050_datasheet]

The best resolution of angular velocity can reach 7.6×10⁻³ ◦∕s, and the best resolution of acceleration can reach 61 × 10⁻⁶ g. Ignoring the noise, these resolutions are totally sufficient for the requirements. Both the sampling rate and communication speed satisfy our requirements. The primary limitation of this IMU is the inherent sensor noise or drift. Considering the noise, we can try to process the signal (such as low-pass filter or quaternion) to get high enough resolution.

### 3.2.2. The central processor

Arduino UNO is chosen as the processor. We can use it to get data from the IMU, process the data, and control the action driver. Its key parameters are listed in Table 2:

Parameter | Value | Unit
# Digital I/O Pins | 14

# Analog Input Pins | 6

# PWM Pins | 6

Supported Communication | I

2C, SPI, UART
Clocking Speed | 16 | MHz
Power Output Voltage | 3.3, 5 | V
Power Input Voltage | 7 ∼ 12 | V

Table 2. The key parameters of Arduino UNO [arduino_uno_datasheet]

The number of digital, analog and PWM pins are enough for the wiring connecting the processor to the sensor and the action driver. The high processing speed is ideal for our control logic. Using I

2C
communication and 3V3 output power, it can match the MPU-6050 very well. However, the power output voltage may not be enough for some action drivers. So a shared power supply may be required.

### 3.2.3. The action driver

We choose to use a L298N motor driver and two geared DC motors. The key parameters of the L298N motor driver are listed in Table 3:

Parameter | Value | Unit
Digital Input Pins | IN1 + IN2, IN3 + IN4
PWM Input Pins | ENA, ENB
Logic Input Voltage | 5 | V
Power Output Voltage | 3.2 ∼ 40 | V
Power Input Voltage | 5 ∼ 35 | V

Table 3. The key parameters of L298N motor driver [l298n_datasheet]

The motor driver allows PWM input, which matches well with the Arduino UNO. The digital input pins can be used to control the direction of motors, while the PWM input pins can be used to control the speed. The required voltage is high as expected, so a good power supply is needed. However, by experiments, we found that the motors can keep still when the speed signal is small, which is caused by the internal static friction. Feed-forward controller can be added to solve this dead-band. Moreover, the two motors have a little asymmetry, which makes the robot yaw. Therefore, stepper motors can be required when we need to do precise control or measurement.

### 3.2.4. Power supply

We need to supply power to both the Arduino UNO and the motor driver. Therefore, two 800mAh 3.7V rechargeable Li-ion cells are used. For reusability, we use a breadboard to transfer the power from batteries to the two components instead of soldering the wires. The safe charged voltage of Li-ion is 2.8 ∼ 4.2 V. By testing, the batteries need to be recharged after working for about 10 hours.

### 3.2.5. Wiring structure

As mentioned above, the electronic components used are:

- MPU-6050 IMU
- Arduino UNO
- L298N motor driver
- Geared DC motors
- Li-ion Batteries
- Breadboard

The wiring method is shown in Fig. 2.

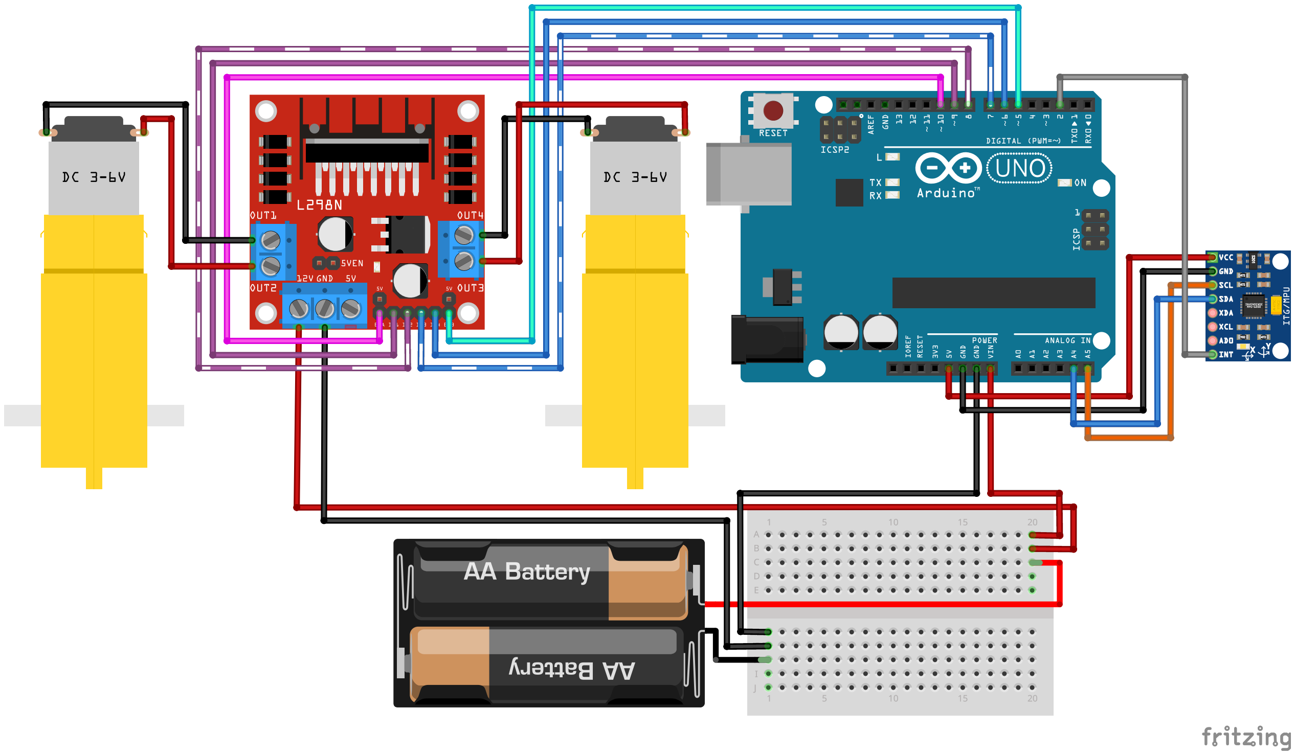
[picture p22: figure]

Figure 2. Wiring diagram of the electronic components. The battery and breadboard are used to power the Arduino UNO and L298N motor driver. UNO communicates with MPU-6050 inertial measurement unit (IMU) using I2C protocol, and sends analog signal to the motor driver using pulse width modulation (PWM). The motor driver controls 2 motors.

2

### 3.3. Mechanical Design

### 3.3.1. Physical model analysis

Fig. 3 shows the simplified physical model of the robot. We can use Lagrangian mechanics to analyze the relationship between F and θ, x. The system Lagrangian and Euler–Lagrange equations are given by:

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
(ẋ + lθ̇ cos θ)

2 + (lθ̇ sin θ)
2

]
− mgl cos θ (1)

d

dt

∂L

∂ẋ

−

∂L
∂x = F | ⇐⇒ | (M + m)ẍ + mlθ̈ cos θ − mlθ̇ ² | sin θ = F

(2)

d

dt

∂L

∂θ̇

−

∂L
∂θ = 0 | ⇐⇒ | ẍ cos θ + lθ̈ − g sin θ = 0 | (3)
M | F

θ

| m

g

x

l

Figure 3. A simplified physical model of the robot. Constrain the movement in 1 dimension. THe model consists of a wheel with mass M, a body mass center m, and a light stick connecting these two with length l. The action of wheel is simplified as a force F. Assume the robot is at position x and its pitch angle is θ.

Usually, we care about the dynamic of θ, which can be derived from Equation 2 and Equation 3:

θ̈ =

(M + m)g sin θ − F cos θ

(M + m sin²
θ)l

−

mθ̇ ²
sin 2θ

2(M + m sin²
θ)

(4)

According to the model Fig. 3 and this Equation 4, we can analyze some cases:

- The robot is perfectly at the balanced state, but a perturbation happens before the controller realizes it (i.e., θ ⪆ 0, F = θ̇ = 0). In this case, θ̈ ≈

(M+m)g sin θ

lM

. To maximize the controller’s temporal response window before θ reaches an unbalanceable angle, we want θ̈ to be as small as possible, which means we need to use small m and/or large l.
- The robot is in a state of dynamic equilibrium (i.e., θ > 0, θ̈ ≈ θ̇ ≈ 0). To keep a constant θ, it’s necessary to make F = (M + m)g tan θ. However, because of the limit of motor power, F can be maintained for only a short time before the large speed brings large resistance. So we should make F > (M + m)g tan θ to bring back balance before the saturation of motors.
- The robot is severely unbalanced (i.e., θ > 0, θ >̇ 0). In this case, the only possible way to balance the robot is to make θ̈ as negative as possible (i.e., θ ≪̈ 0). To achieve this, we need to use a combination of large F > (M + m)g tan θ and small l.
- The robot is inverted (i.e., 90◦ < θ < 270◦
(l < Rwheel), l = 0, or
m = 0). Now the robot is impossible to return to the desired balanced state (or the balanced state can’t be defined), but becomes permanently stable.

In conclusion, a motor being able to produce huge F is wanted for all the cases. Similarly, it’s good to have small m, M, and/or m

M

. Large l
is suitable for peaceful environment and high balance performance, while small l or inverted robot is suitable for severe environment and high controllability.

### 3.3.2. Chassis

We use CAD (Autodesk Fusion) to design the chassis model, and 3Dprint the model. The chassis is designed with many components in the experimental stage to make some components easier to update. These components are assembled using M3 bolts and nuts. For the final design, all the components are combined into a whole one to make the chassis stable.
In Fusion, the chassis is designed with the help of the models of other electronic components. Official datasheets of the electronic components are also used. In this way, it’s precise and accurate to design the size and position of chassis components and through holes. One of our CAD model designs is shown in Fig. 4. It has high mass center, which can perform good balancing skill but lack flexibility.

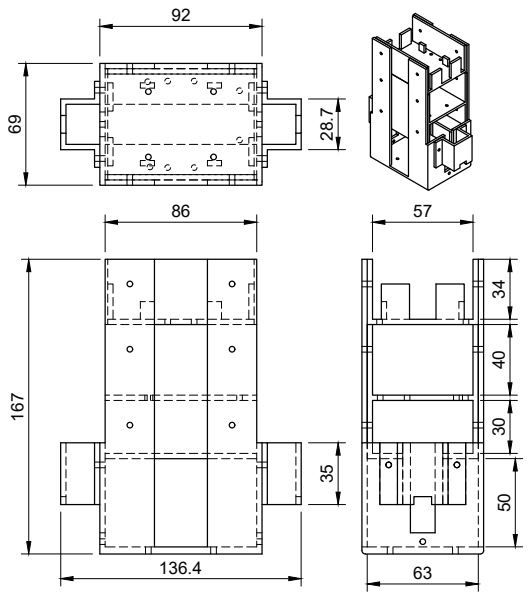
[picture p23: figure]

(a) Front-top-side view

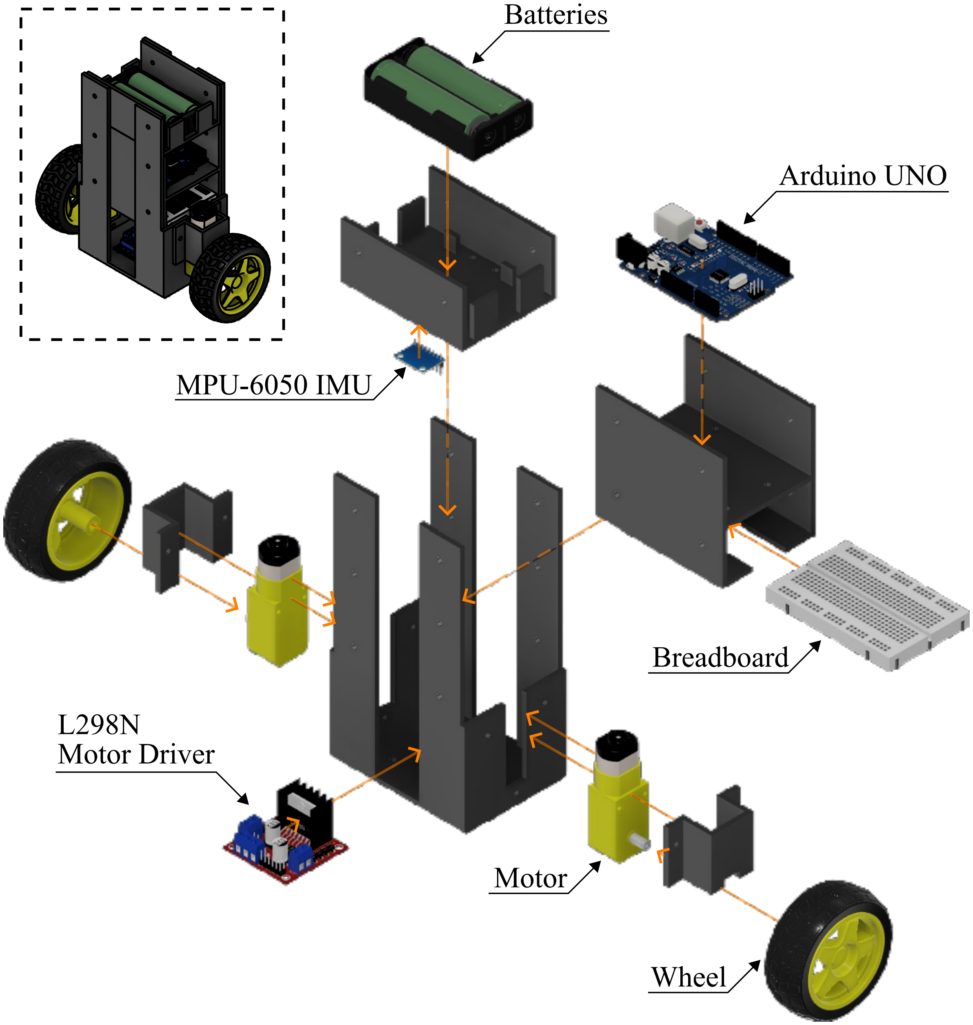
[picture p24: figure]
Batteries; Arduino UNO; Breadboard; L298N Motor Driver; MPU-6050 IMU; Motor; Wheel

(b) Robot components and assembly

Figure 4. A chassis model design.

PrusaSlicer is used to convert CAD models to 3D-printing code.

3

The printer uses PLA as the filament with diameter of 1.75mm. To make our chassis sturdy, we use layer height of 0.3mm. The vertical shells is set to 4 perimeters, and the horizontal shells is set to 4 top layers and 4 bottom layers. Since most of our chassis consist of plates of 3mm, these parameters are sufficient to make our chassis solid. The fill density is set to 15%. The only disadvantage is that solid chassis may increase the mass. We compensated it by change the height of mass center by a larger value.

### 3.4. Signal Processing

### 3.4.1. IMU data processing

To get the robot state, we need to process the data from the IMU. The IMU contains a 3-axis gyroscope used to measure angular velocity and a 3-axis accelerometer used to measure acceleration. One important thing we can do is to get the angle (yaw, pitch, roll) from these values. Simply, we can integrate the 3 angular velocities (ωx

, ωy

, ωz

) to get
the corresponding Euler angle. However, Euler angles suffer from Gimbal Lock, resulting in the loss of a degree of freedom and causing ambiguous calculations (for example, the results are the same whether it yaws by 30◦

and then pitches by 90◦

, or pitches by 90◦
and then rolls
by 30◦
, which makes it difficult to determine the true yaw or roll angle). Because of this, we use quaternion q = (q0

, q1

, q2

, q3

) to represent the
angle state, which indicates the current state that is equivalent to rotate the initial state around an axis (q1

, q2

, q3

) by an amount of q0
The current quaternion is given by:

qn = qn−1 +

∆t

2

⋅ qn−1 ⊗ ω | (5)

Another method to get quaternion is using the accelerations
(ax

, ay

, az

). Because there is a constant gravity of ≈ 9.8m ⋅s | −2, we can
know the quaternion by comparing the direction of measured acceleration with the true gravity. However, this method is noisy, while using gyroscope can produce drift over a long time. We can mitigate the high-frequency noise of accelerometers by a low-pass filter, and the low-frequency drift of gyroscopes by a high-pass filter, which is called complementary filter.
There are many states we can calculate from the quaternion (Most calculations can be done by the IMU module or some libraries such as i2cdevlib/Arduino/MPU6050). For example:

Pitch: θ = arcsin (2(q0q2 − q3q1

)) | (6)

Yaw: ψ = arctan

2(q0q3 + q1q2

) 1 − 2(q
2 2 + q 2/3) | (7)

Acceleration: aworld = q ⊗ (0, ax

, ay

, az

) ⊗ q⁻¹ | (8)

In this way, we can get the tilt angles or accelerations much more precisely and unambiguously. However, to get the displacement of the robot, we need to integrate the acceleration twice, which can brings huge noise and drift. This disadvantage is mostly caused by the hardware, which is hard to improve by software. Therefore, we can choose to calculate the displacement from the signal used to control the speed of motors.

### 3.4.2. PID controller

PID (Proportional-Integral-Derivative) controller is the core of the feedback system. By comparing the current state S(t) with the desired state, we get an error term e(t). Using e(t) as the input of PID controller, we can use the output u(t) to drive the current state toward the desired state. The output expression is given by:

u(t) = Kpe(t) + Ki ∫

t

0

dτ e(τ) + Kd

de(t)
dt | (9)

The Proportional term means that the larger the error is, the large the output is to restore the state. The Integral term means that the longer the error persists, the large the output is to further restore the state. The Derivative term means that the faster the error decreases, the smaller the output is to reduce oscillation. The three terms have individual coefficients (Kp

, Ki

, Kd
). Their combinations vary widely across different situations.
For the PID of balancing pitch angle, the 3 coefficients need to be tune along with the balanced pitch angle θ0
. First, we found the
approximate pitch angle. Based on this, we adjusted only θ0 and Kp until the robots fell in both directions with a similar low probability, which means θ0
is closed to the true balanced pitch angle. Then, we tuned Kd
such that the robot wouldn’t oscillate too much around the
θ0
. However, the robot may occasionally keep moving in one direction. We used large Ki
to correct it. The optimal tuning yields highly varied coefficients. For example, Kp = 48, Ki = 600, and Kd = 0.19 with PID sample time = 2ms. By tunning these coefficients and looking for a good balancing state, we can achieve better feedback performance.

### 3.4.3. Pulse width modulation

In order to control the robot smoothly and continuously, we need analog signals to do the task. However, the UNO has only digital output, which means the output voltage can be either HIGH level or LOW level without any values in between. PWM can solve this problem. Instead of encoding signals to voltage level, it produces a train of pulses as the output, and encodes signals to the width of each pulse. Meanwhile, our motor driver is able to receive the PWM signals.
However, the range of PWM values is limited. This disadvantage can be ignored in our cases, since the resolution of PWM is much better than the resolution of geared motors.

### 3.5. Control Logic

The program for controlling runs in Arduino UNO. The structure of control logic is based on 3.1 and Fig. 1, whose details are shown below:

### 3.5.1. Start

In this initialization sequence, all the components are configured. If anyone of them is not initialized successfully, the following controlling code would not run.

- initImu(): Sets the offsets of 3 axises for the gyroscope and the accelerometer, and waits until the IMU becomes stable.
- initPID(): Defines the balanced pitch and yaw, the PID coefficients for different situations, and the PID object for pitch and yaw.
- initMotor(): Uses pinMode(pin, mode) to initialize 2 EN pins and 4 IN pins.

### 3.5.2. Read States

In this process, we get the states of the robot from the calculations about quaternion. The logical code is shown in Code 1 For pitch and yaw angles, we calculate the error between the true angle and the balanced angle, unwrap the 2π period, and use the result as the input of feedback control. For accelerations, we compute the value in the world frame using the quaternion.

double unwrapAngle(float angle, double balanced) { double a = angle * 180 / M_PI - balanced;
// ... unwrap from 2*pi ...
}
bool getRobotState() {
imu.dmpGetQuaternion(&quaternion, imuFifoBuffer); imu.dmpGetYawPitchRoll(imuYpr, &quaternion, &gravity); pitchAngle = unwrapAngle(imuYpr[1], balancedPitch); // ... doing similar jobs for yaw and acceleration ... imu.dmpGetLinearAccelInWorld(...);

4

}

Code 1. Example code of "Read States" process

### 3.5.3. Check States

The states gotten from the previous process is analyzed, and the next step is determined. For example (as shown in Code 2), the coefficients of PID controller will dynamically transition to surviving mode (highgain feedback) if the pitch angle is too large, or the motors will be disabled if the robot is destined to fall.

if (abs(pitchAngle) > maxPitchAngle) { motorStop(); } // ...
if (abs(pitchAngle) > survivingPitch) { pitchPID.SetTunings(sKp, sKi, sKd);
} else { pitchPID.SetTunings(kp, ki, kd); }

Code 2. Example code of "Check States" process

### 3.5.4. Feedback Control

Our feedback control is currently based on only PID controller. We use a library to manage the computing. In the code, the feedback output can be gotten from pid.Compute(). The code is simple, while this process is essential to the robot. All the coefficients need plenty of time to tune manually.

### 3.5.5. Take Action

This process convert the digital signals from feedback control into a real action of the robots. For example, accelerating immediately, or rotating clockwise slowly. The action is also influenced by "Check States". As shown in Code 3, balancing the pitch is a priority over adjusting the yaw.

if (abs(motorValue) > maxMotorValue * 0.3) { motorMove(motorValue, ENA_PIN, IN1_PIN, IN2_PIN); motorMove(motorValue, ENB_PIN, IN3_PIN, IN4_PIN); } else {
motorMove(motorValue + yawCorrection, ENA_PIN, ...); motorMove(motorValue - yawCorrection, ENB_PIN, ...); }

Code 3. Example code of "Take Action" process

### 4. PROTOTYPE PROGRESS
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

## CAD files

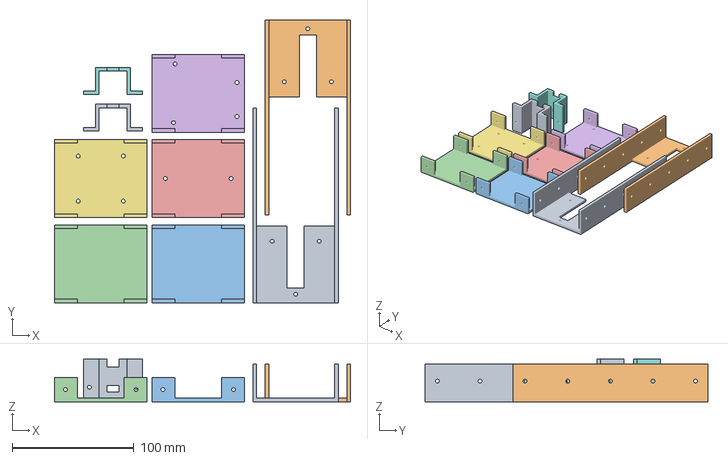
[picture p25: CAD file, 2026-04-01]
models/model-2-Assembly3D-print-layout.3mf
243.0 x 232.0 x 35.0 mm

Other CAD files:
models/model-2.FCStd

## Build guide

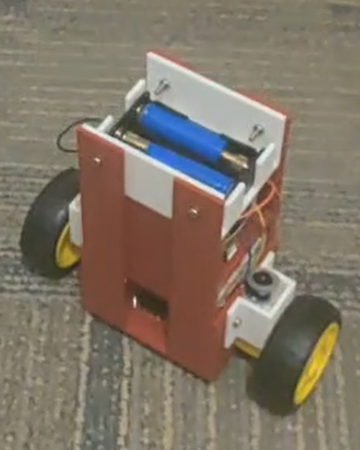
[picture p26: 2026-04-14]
Presentation/Figures/assembled_robot.png

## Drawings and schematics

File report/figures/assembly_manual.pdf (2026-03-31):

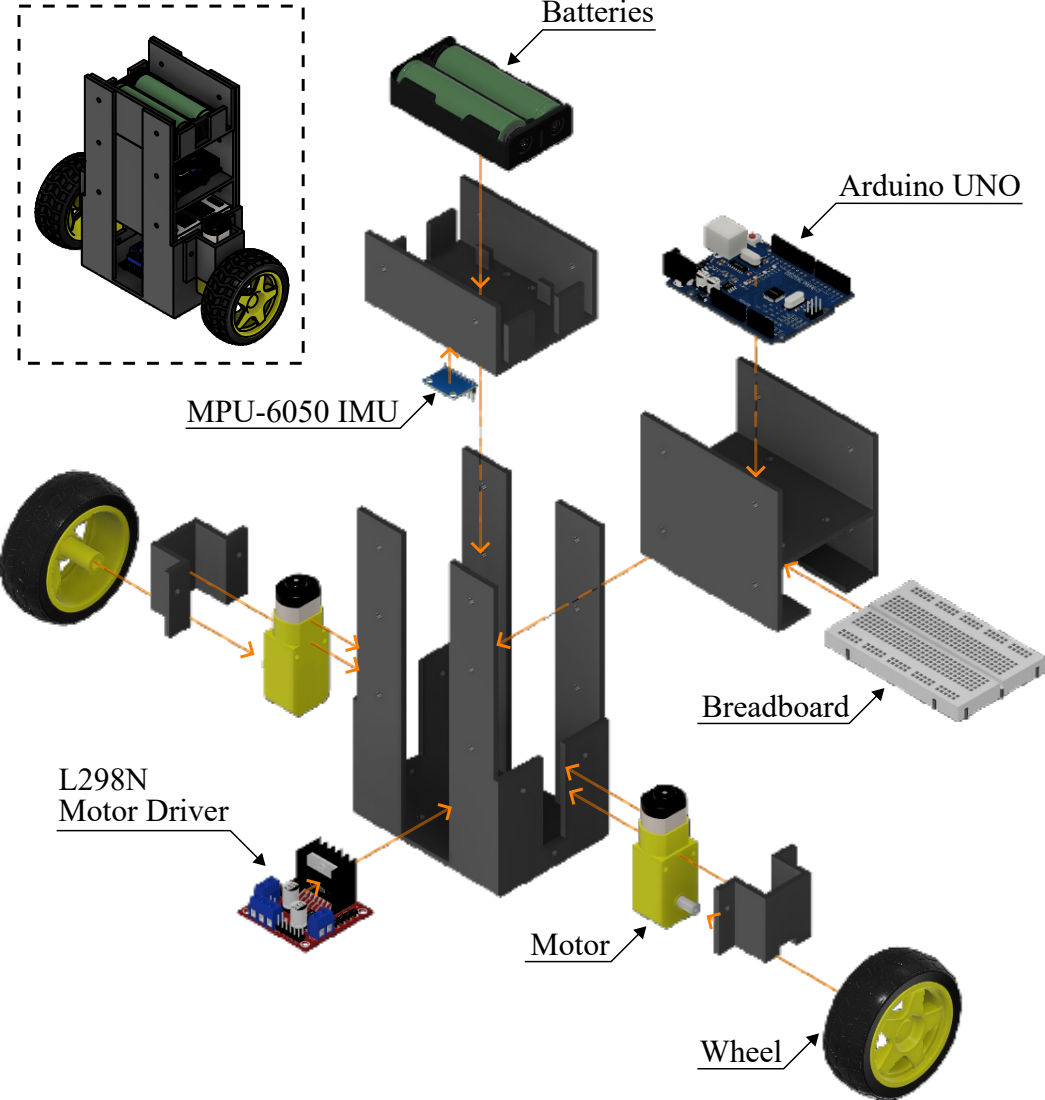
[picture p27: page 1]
Batteries; Arduino UNO; Breadboard; L298N Motor Driver; MPU-6050 IMU; Motor; Wheel

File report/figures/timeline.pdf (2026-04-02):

Week 7 | Week 8 | Week 9 | Week 10 | Week 11 | Week 12

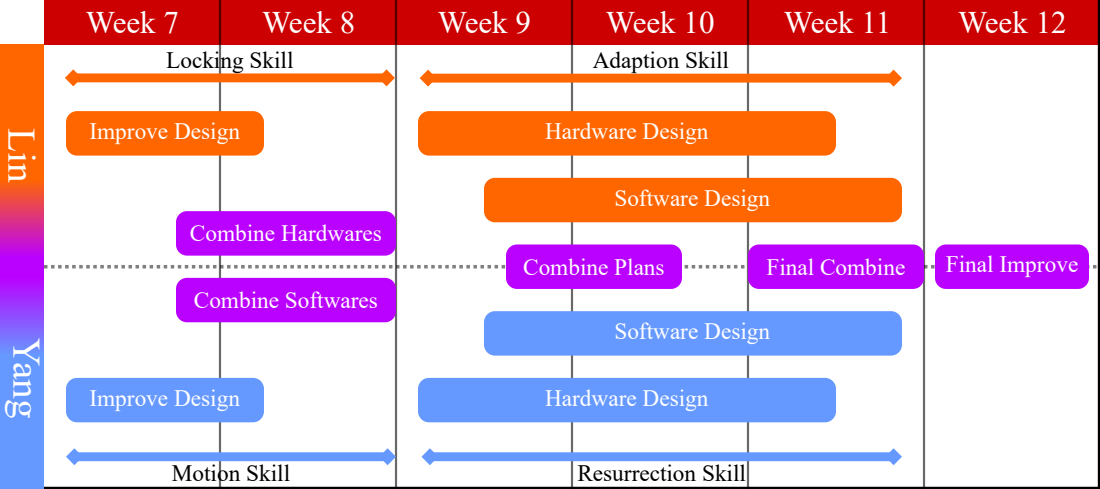
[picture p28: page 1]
Lin Yang; Improve Design; Hardware Design; Software Design; Combine Hardwares; Combine Softwares; Combine Plans; Final Combine; Final Improve; Locking Skill; Motion Skill; Resurrection Skill; Adaption Skill

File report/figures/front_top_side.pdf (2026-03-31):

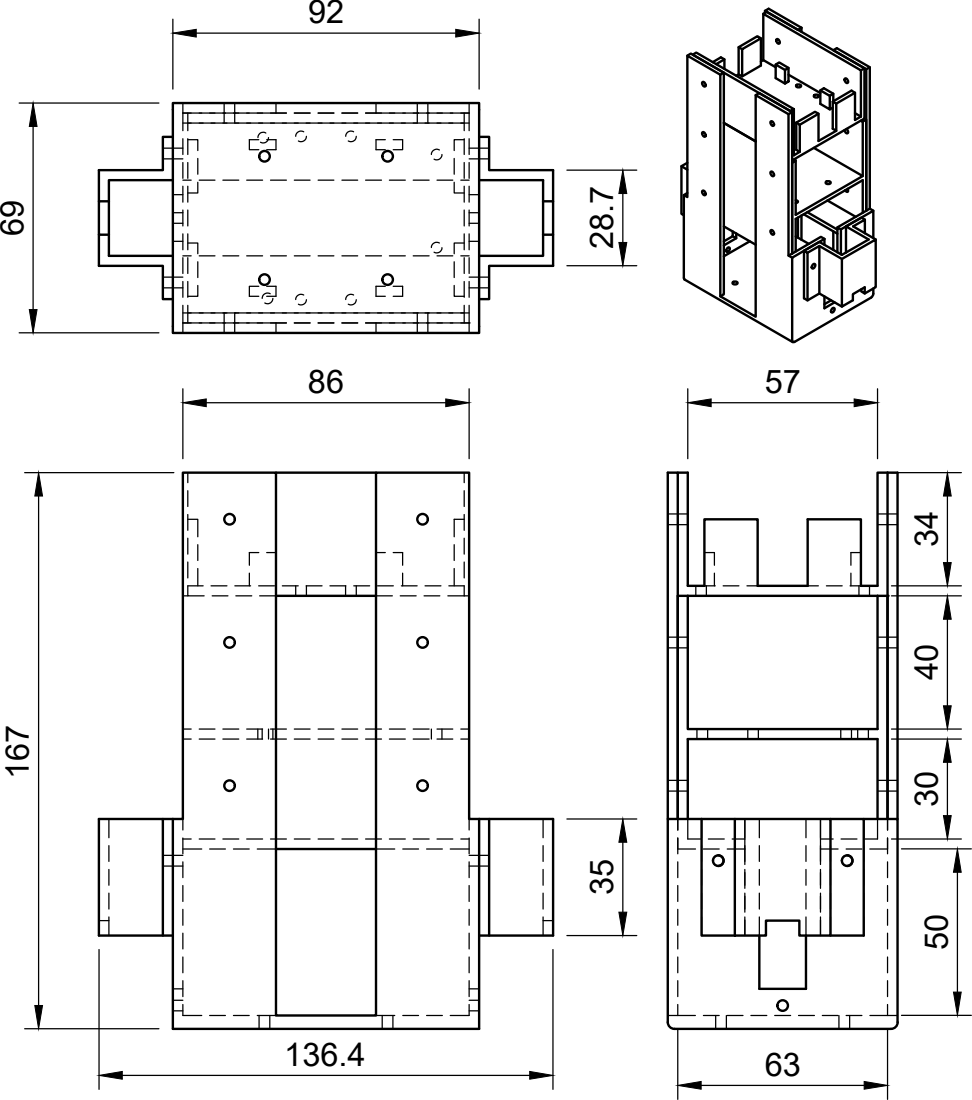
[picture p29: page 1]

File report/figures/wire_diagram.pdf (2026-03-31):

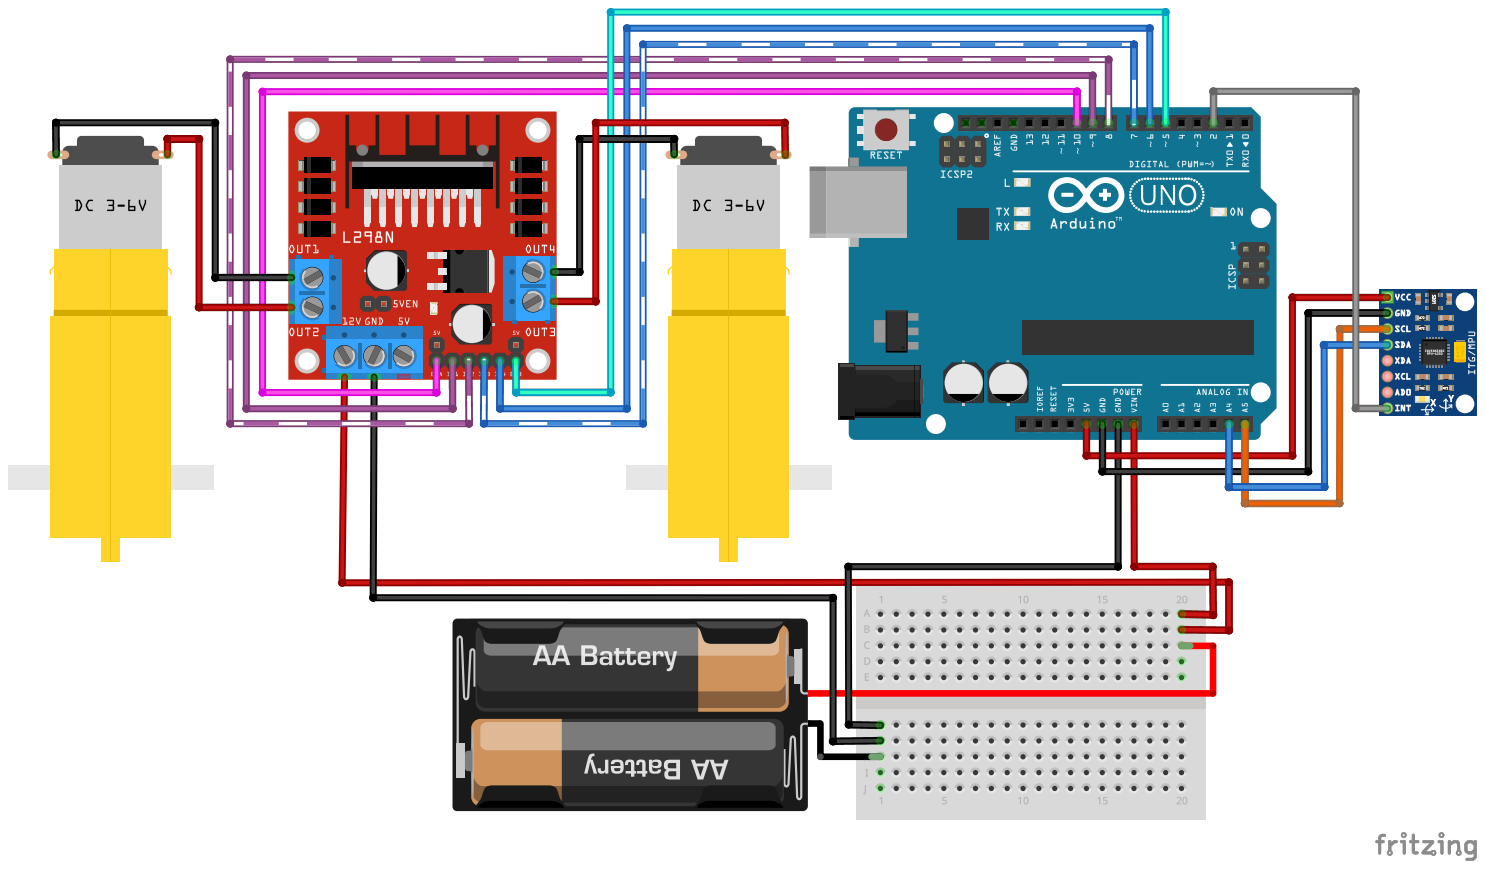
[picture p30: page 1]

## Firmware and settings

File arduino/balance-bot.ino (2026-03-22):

#include "I2Cdev.h"
#include "MPU6050_6Axis_MotionApps20.h"
#include <PID_v1.h>

#define IMU_INT_PIN 2

#define MOTOR_ENA_PIN 5
#define MOTOR_IN1_PIN 6
#define MOTOR_IN2_PIN 7

#define MOTOR_ENB_PIN 10
#define MOTOR_IN3_PIN 8
#define MOTOR_IN4_PIN 9

bool setupSuccess = true;

MPU6050 imu;
volatile bool imuHasData = false;
uint16_t imuDataSize;
uint8_t imuFifoBuffer[256];
Quaternion imuQuaternion;
VectorFloat imuGravity;
VectorInt16 imuAngularVelocity;
float imuYpr[3];
unsigned long imuIdx = 0;
const int16_t imuXGyroOffset = 86;
const int16_t imuYGyroOffset = 67;
const int16_t imuZGyroOffset = 29;
const int16_t imuZAccelOffset = 969;

double balancedAngle = 87.16;
double Kp = 46;
double Ki = 0;
double Kd = 0.15;
// double Kp = 4.6;
// double Ki = 0;
// double Kd = 0.026;
double angle;
double motorValue;
PID pid(&angle, &motorValue, &balancedAngle, Kp, Ki, Kd, DIRECT);
const double maxAngle = 40;

void imuInterrupt() {
  imuHasData = true;
}

bool connectImu() {
  Serial.print(F("Connecting IMU..."));

  imu.initialize();

  bool imuDmpError = imu.dmpInitialize();
  if (imuDmpError) {
    Serial.println(F("DMP error"));
    return false;
  }

  imu.setXGyroOffset(imuXGyroOffset);
  imu.setYGyroOffset(imuYGyroOffset);
  imu.setZGyroOffset(imuZGyroOffset);
  imu.setZAccelOffset(imuZAccelOffset);

  imu.setDMPEnabled(true);

  attachInterrupt(digitalPinToInterrupt(IMU_INT_PIN), imuInterrupt, RISING);

  imu.resetFIFO();

  Serial.println(F("Connected"));

  return true;
}

bool connectPID() {
  Serial.print(F("Connecting PID..."));

  pid.SetMode(AUTOMATIC);
  pid.SetSampleTime(2);
  // pid.SetOutputLimits(-5, 5);
  // pid.SetOutputLimits(-255, 255);
  pid.SetOutputLimits(-15.9, 15.9);

  Serial.println(F("Connected"));

  return true;
}

bool connectMotor() {
  Serial.print(F("Connecting Motor..."));

  pinMode(MOTOR_ENA_PIN, OUTPUT);
  pinMode(MOTOR_ENB_PIN, OUTPUT);
  pinMode(MOTOR_IN1_PIN, OUTPUT);
  pinMode(MOTOR_IN2_PIN, OUTPUT);
  pinMode(MOTOR_IN3_PIN, OUTPUT);
  pinMode(MOTOR_IN4_PIN, OUTPUT);

  analogWrite(MOTOR_ENA_PIN, 0);
  analogWrite(MOTOR_ENB_PIN, 0);
  digitalWrite(MOTOR_IN1_PIN, LOW);
  digitalWrite(MOTOR_IN2_PIN, LOW);
  digitalWrite(MOTOR_IN3_PIN, LOW);
  digitalWrite(MOTOR_IN4_PIN, LOW);

  Serial.println(F("Connected"));

  return true;
}

bool getImuAngle() {
  if (!imu.dmpGetCurrentFIFOPacket(imuFifoBuffer)) {
    return false;
  }

  imuHasData = false;

  imu.dmpGetQuaternion(&imuQuaternion, imuFifoBuffer);
  imu.dmpGetGravity(&imuGravity, &imuQuaternion);
  imu.dmpGetYawPitchRoll(imuYpr, &imuQuaternion, &imuGravity);

  angle = imuYpr[1] * 180 / M_PI;
  angle += (angle > 0 ? -180 : 180);

  return true;
}

void getMotorValue() {
  pid.Compute();

  if (imuIdx % 1 == 0) {
    Serial.print(-250);
    Serial.print(F("\t"));
    Serial.print(250);
    Serial.print(F("\t"));
    Serial.print(angle);
    Serial.print(F("\t"));
    // Serial.println(motorValue);
    Serial.println(motorValue*motorValue);
  }
  imuIdx += 1;
}

void driveMotor() {
  if (abs(angle - balancedAngle) > maxAngle || motorValue==0) {
    motorStop();
    return;
  }

  if (motorValue > 0) {
    motorForward();
  } else {
    motorBackward();
  }
}

void motorStop() {
  analogWrite(MOTOR_ENA_PIN, 0);
  analogWrite(MOTOR_ENB_PIN, 0);
  digitalWrite(MOTOR_IN1_PIN, LOW);
  digitalWrite(MOTOR_IN2_PIN, LOW);
  digitalWrite(MOTOR_IN3_PIN, LOW);
  digitalWrite(MOTOR_IN4_PIN, LOW);
}
void motorForward() {
  analogWrite(MOTOR_ENA_PIN, motorValue*motorValue);
  analogWrite(MOTOR_ENB_PIN, motorValue*motorValue);
  digitalWrite(MOTOR_IN1_PIN, HIGH);
  digitalWrite(MOTOR_IN2_PIN, LOW);
  digitalWrite(MOTOR_IN3_PIN, HIGH);
  digitalWrite(MOTOR_IN4_PIN, LOW);
}
void motorBackward() {
  analogWrite(MOTOR_ENA_PIN, motorValue*motorValue);
  analogWrite(MOTOR_ENB_PIN, motorValue*motorValue);
  digitalWrite(MOTOR_IN1_PIN, LOW);
  digitalWrite(MOTOR_IN2_PIN, HIGH);
  digitalWrite(MOTOR_IN3_PIN, LOW);
  digitalWrite(MOTOR_IN4_PIN, HIGH);
}


void setup() {
  Serial.begin(115200);

  setupSuccess &= connectImu();

  setupSuccess &= connectPID();

  setupSuccess &= connectMotor();

  Serial.print(F("Setup succeed: "));
  Serial.println(setupSuccess);
}


void loop() {
  if (!setupSuccess) { return; }

  if (!imuHasData) { return; }

  if (!getImuAngle()) { return; }

  getMotorValue();

  driveMotor();
}

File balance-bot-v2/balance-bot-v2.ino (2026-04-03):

#include "gy-87-fusion.h"
#include <Adafruit_AHRS.h>
#include <AdvancedPID.h>
#include <L298NX2.h>

const int FILTER_UPDATE_RATE_HZ = 100; // 5000?
const float maxAngle = 45;

// Uno can probably only use the fastest
// pick your filter! slower == better quality output
// Adafruit_NXPSensorFusion filter; // slowest
// Adafruit_Madgwick filter;  // faster than NXP
Adafruit_Mahony filter; // fastest/smalleset

GY87Fusion imu;
AdvancedPID stab_pid(2.5, 0.0, 0.15, 0.0);

uint32_t timestamp;

void setup() {
  // Standalone project, serial not necessary
  Serial.begin(115200);

  // We already prints the errors, so no need to print success bit.
  imu.begin(FILTER_UPDATE_RATE_HZ, &filter);

  timestamp = millis();
  Wire.setClock(400000); // 400KHz
}

void loop() {
  if ((millis() - timestamp) < (1000 / FILTER_UPDATE_RATE_HZ)) {
    return;
  }
  timestamp = millis();

  float gyro_y;
  float pitch;
  imu.get_gyro_and_pitch(&gyro_y, &pitch);
}

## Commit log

2026-03-16 Chassis model
    [20260314_111740.3mf]
2026-03-22 Chassis model (v2)
    [20260314_111740_2.3mf]
2026-03-22 Add Arduino script
2026-03-31 Clean up and re-organize
    [20260314_111740.3mf, 20260314_111740_2.3mf]
2026-03-31 Add new model
    Ported the Fusion model to FreeCAD, made some changes / improvements as well.
    Fusion online is sooo slow and unusable / buggy (each instance seems to be running in a Windows VM served through RDP...). And Fusion uses propriatery format while FreeCAD's format is open.
    [model-2.FCStd]
2026-03-31 Add report
    [Untitled Sketch.fzz]
2026-04-01 Fix model
    - Make model more printer friendly (no overhang recess on the edge)
    - Fix a screw hole position error
    - Fix battery holder screw hole postition
    [model-2.FCStd]
2026-04-01 Add printer file
    Also included the 3D printer layout in the model's assemby.
    [model-2-Assembly3D-print-layout.3mf, model-2.FCStd]
2026-04-02 Add v2 code
    Unfinished, added 9-axis fusion for GY-87 to eliminate yaw drift.
    [balance-bot-v2.ino]
2026-04-03 Update Yaw Correction
2026-04-03 Allow user defined filter
